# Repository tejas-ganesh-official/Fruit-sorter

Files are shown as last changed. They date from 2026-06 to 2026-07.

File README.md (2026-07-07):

# Fruit Sorter

AI-powered fruit sorting machine. An **ESP32-CAM** watches for fruit with an ultrasonic
sensor, snaps a photo, and sends it to a Telegram bot. A PC picks up the photo, classifies
it with a **PyTorch EfficientNetV2-S** model (`damaged` / `old` / `ripe` / `unripe`), and
tells a second **ESP32** to drive servo gates that drop the fruit into the correct bin
through a 3D-printed Y-chute.

---

## How it works

```mermaid
flowchart LR
    A[HC-SR04<br/>ultrasonic] -->|object detected| B[ESP32-CAM<br/>esp32cam_capture.ino]
    B -->|photo via HTTPS| C[Telegram bot]
    C -->|new photo| D[PC<br/>inference.py]
    D -->|EfficientNetV2-S<br/>predict label| D
    D -->|HTTP GET /data?label=&conf=| E[ESP32<br/>esp32_sorter.ino]
    E -->|drive servos| F[Y-chute<br/>Y_shape_v1.stl]
```

**Sorting logic** (`esp32_sorter.ino`):

| Prediction | Action | Bin |
|---|---|---|
| `old`, `damaged`  | Servo 1 | reject |
| `ripe`, `unripe`  | Servo 2 | keep |

> All three parts — ESP32-CAM, ESP32, and the PC running `inference.py` — must be on the
> **same Wi-Fi network**.

---

## Repository layout

```
fruit-sorter/
├── firmware/
│   ├── esp32cam_capture/      # AI-Thinker ESP32-CAM: ultrasonic trigger + photo -> Telegram
│   │   └── esp32cam_capture.ino
│   └── esp32_sorter/          # ESP32: receives label over HTTP, drives sorting servos
│       └── esp32_sorter.ino
├── ml/
│   ├── train.py               # PyTorch EfficientNetV2-S trainer (produces the .pth used below)
│   ├── inference.py           # Telegram listener + classifier + sends result to the sorter ESP32
│   ├── train_tf_mobilenet.py  # ALTERNATE trainer (TensorFlow/MobileNetV2) — see "Known gaps"
│   ├── requirements.txt       # main pipeline deps (PyTorch)
│   └── requirements-tf.txt    # only for the alternate TF trainer
├── hardware/
│   ├── wiring_diagram.png     # HC-SR04 <-> ESP32-CAM wiring
│   └── Y_shape_v1.stl         # 3D-printable sorting chute
├── LICENSE
└── README.md
```

---

## Wiring

HC-SR04 → ESP32-CAM (pins per `esp32cam_capture.ino`):

| HC-SR04 | ESP32-CAM |
|---|---|
| VCC | 5V |
| TRIG | GPIO 12 |
| ECHO | GPIO 14 |
| GND | GND |

Sorting servos → ESP32 (pins per `esp32_sorter.ino`):

| Servo | ESP32 |
|---|---|
| Servo 1 | GPIO 18 |
| Servo 2 | GPIO 19 |

> ⚠️ **ECHO is 5V logic, the ESP32 GPIO is 3.3V.** Put a divider on the ECHO line
> (e.g. 1kΩ + 2kΩ) or a level shifter so you don't stress the pin over time.

---

## Setup

### 1. Train the model (optional — only if you don't already have a `.pth`)

Arrange your images as an `ImageFolder`, one sub-folder per class:

```
dataset/
├── damaged/
├── old/
├── ripe/
└── unripe/
```

```bash
cd ml
pip install -r requirements.txt
python train.py --data ./dataset --epochs 15 --out fruit_efficientnetv2s.pth
```

This saves a checkpoint `inference.py` can load directly
(`{"model_state_dict": ..., "classes": [...]}`).

### 2. Flash the firmware (Arduino IDE)

Open each sketch from its own folder and fill in the blanks at the top:

- `firmware/esp32cam_capture/esp32cam_capture.ino` — Wi-Fi SSID/password, `BOTtoken`, `CHAT_ID`.
  Board: **AI Thinker ESP32-CAM**. Needs the `esp32` board package.
- `firmware/esp32_sorter/esp32_sorter.ino` — Wi-Fi SSID/password.
  Needs the **ESP32Servo** library. Note the local IP it prints on boot.

### 3. Run inference on the PC

```bash
cd ml
pip install -r requirements.txt
```

Fill in the config block at the top of `inference.py`:

- `api_id`, `api_hash` — from https://my.telegram.org
- `BOT_USERNAME` — your bot's username
- `MODEL_PATH` — path to your `.pth`
- `SAVE_DIR` — where incoming photos get saved
- `ESP32_IP` — the IP printed by `esp32_sorter.ino`

```bash
python inference.py
```

It listens for photos from your bot, classifies each one, and forwards the result to the
sorter ESP32.

---

## Known gaps / TODO

- **Two training scripts, two frameworks.** `train.py` is PyTorch (EfficientNetV2-S) and
  matches `inference.py`. `train_tf_mobilenet.py` is TensorFlow (MobileNetV2) and saves a
  `.h5` that **`inference.py` cannot load as-is** — it's kept as a reference/alternate only.
  If you want the TF path to be end-to-end, you'd need a matching TF inference script or an
  `.h5 → PyTorch` conversion. Use `train.py` for the working loop.
- **Secrets are placeholders.** Don't commit real Telegram/Wi-Fi credentials. The
  `.gitignore` already excludes the Telethon `*.session` file (it holds a login token for
  your Telegram account) and model weights.
- **Distance window is 1–5 cm** in `esp32cam_capture.ino` — tune `getDistance()` thresholds
  to your rig's geometry.
- **Model weights aren't included.** They're gitignored (large binaries). Ship them via a
  GitHub Release or Git LFS if you want them in the repo.

---

## License

MIT — see [LICENSE](LICENSE).

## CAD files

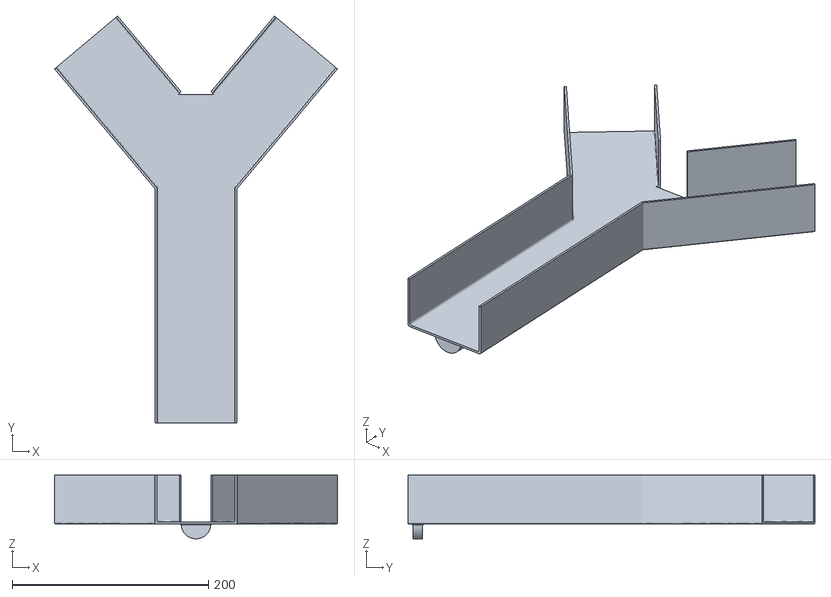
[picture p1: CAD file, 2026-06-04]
hardware/Y_shape_v1.stl
288.8 x 415.3 x 65.0

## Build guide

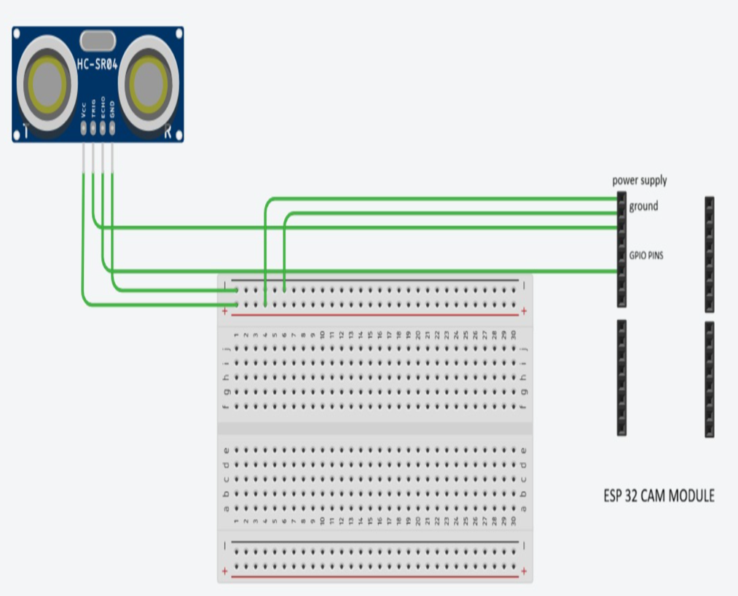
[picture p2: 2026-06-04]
hardware/wiring_diagram.png

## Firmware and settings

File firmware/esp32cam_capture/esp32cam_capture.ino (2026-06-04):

#include "esp_camera.h"
#include <WiFi.h>
#include <WiFiClientSecure.h>

const char* ssid = ""; //enter wifi id
const char* password = ""; //enter wifi password
//note that ESP32, ESP32 cam AND the machine in which you run the fetch_send file must all be in the same network

String BOTtoken = ""; //insert bot token
String CHAT_ID = ""; //insert chat id

WiFiClientSecure client;

// Ultrasonic pins
#define TRIG_PIN 12
#define ECHO_PIN 14

// AI Thinker ESP32-CAM pins
#define PWDN_GPIO_NUM     32
#define RESET_GPIO_NUM    -1
#define XCLK_GPIO_NUM      0
#define SIOD_GPIO_NUM     26
#define SIOC_GPIO_NUM     27
#define Y9_GPIO_NUM       35
#define Y8_GPIO_NUM       34
#define Y7_GPIO_NUM       39
#define Y6_GPIO_NUM       36
#define Y5_GPIO_NUM       21
#define Y4_GPIO_NUM       19
#define Y3_GPIO_NUM       18
#define Y2_GPIO_NUM        5
#define VSYNC_GPIO_NUM    25
#define HREF_GPIO_NUM     23
#define PCLK_GPIO_NUM     22

// -------- WiFi reconnect --------
void ensureWiFi() {
  if (WiFi.status() == WL_CONNECTED) return;

  Serial.println("WiFi reconnecting...");
  WiFi.begin(ssid, password);

  while (WiFi.status() != WL_CONNECTED) {
    delay(500);
    Serial.print(".");
  }

  Serial.println(" connected");
}

// -------- Camera --------
void startCamera() {

  camera_config_t config;

  config.ledc_channel = LEDC_CHANNEL_0;
  config.ledc_timer = LEDC_TIMER_0;

  config.pin_d0 = Y2_GPIO_NUM;
  config.pin_d1 = Y3_GPIO_NUM;
  config.pin_d2 = Y4_GPIO_NUM;
  config.pin_d3 = Y5_GPIO_NUM;
  config.pin_d4 = Y6_GPIO_NUM;
  config.pin_d5 = Y7_GPIO_NUM;
  config.pin_d6 = Y8_GPIO_NUM;
  config.pin_d7 = Y9_GPIO_NUM;

  config.pin_xclk = XCLK_GPIO_NUM;
  config.pin_pclk = PCLK_GPIO_NUM;
  config.pin_vsync = VSYNC_GPIO_NUM;
  config.pin_href = HREF_GPIO_NUM;

  config.pin_sscb_sda = SIOD_GPIO_NUM;
  config.pin_sscb_scl = SIOC_GPIO_NUM;

  config.pin_pwdn = PWDN_GPIO_NUM;
  config.pin_reset = RESET_GPIO_NUM;

  config.xclk_freq_hz = 20000000;
  config.pixel_format = PIXFORMAT_JPEG;

  config.frame_size = FRAMESIZE_UXGA;
  config.jpeg_quality = 10;

  config.fb_count = 1;
  config.fb_location = CAMERA_FB_IN_PSRAM;
  config.grab_mode = CAMERA_GRAB_LATEST;

  esp_err_t err = esp_camera_init(&config);

  if (err != ESP_OK) {
    Serial.printf("Camera init failed: 0x%x\n", err);
    return;
  }

  Serial.println("Camera initialized");
}

// -------- Distance --------
float getDistance() {

  digitalWrite(TRIG_PIN, LOW);
  delayMicroseconds(2);

  digitalWrite(TRIG_PIN, HIGH);
  delayMicroseconds(10);

  digitalWrite(TRIG_PIN, LOW);

  long duration = pulseIn(ECHO_PIN, HIGH, 30000);

  float distance = duration * 0.034 / 2;

  return distance;
}

// -------- Send Photo --------
bool sendPhoto() {

  delay(200);

  // Flush old buffered frames
  camera_fb_t * fb = NULL;

  for (int i = 0; i < 3; i++) {

    fb = esp_camera_fb_get();

    if (fb) {
      esp_camera_fb_return(fb);
      fb = NULL;
    }

    delay(100);
  }

  // Capture fresh frame
  fb = esp_camera_fb_get();

  if (!fb) {
    Serial.println("Camera capture failed");
    return false;
  }

  Serial.println("Connecting to Telegram...");

  if (!client.connect("api.telegram.org", 443)) {

    Serial.println("Telegram connection failed");

    esp_camera_fb_return(fb);

    return false;
  }

  String head =
    "--ESP32\r\n"
    "Content-Disposition: form-data; name=\"chat_id\";\r\n\r\n" +
    CHAT_ID +
    "\r\n--ESP32\r\n"
    "Content-Disposition: form-data; name=\"photo\"; filename=\"esp32.jpg\"\r\n"
    "Content-Type: image/jpeg\r\n\r\n";

  String tail = "\r\n--ESP32--\r\n";

  uint32_t totalLen = fb->len + head.length() + tail.length();

  client.println("POST /bot" + BOTtoken + "/sendPhoto HTTP/1.1");
  client.println("Host: api.telegram.org");
  client.println("Content-Length: " + String(totalLen));
  client.println("Content-Type: multipart/form-data; boundary=ESP32");
  client.println();

  client.print(head);

  client.write(fb->buf, fb->len);

  client.print(tail);

  esp_camera_fb_return(fb);

  client.stop();

  Serial.println("Fresh photo sent");

  return true;
}

void setup() {

  Serial.begin(115200);

  pinMode(TRIG_PIN, OUTPUT);
  pinMode(ECHO_PIN, INPUT);

  Serial.println();
  Serial.println("Connecting to WiFi...");

  WiFi.begin(ssid, password);

  while (WiFi.status() != WL_CONNECTED) {
    delay(500);
    Serial.print(".");
  }

  Serial.println();
  Serial.println("WiFi connected");

  Serial.print("IP Address: ");
  Serial.println(WiFi.localIP());

  client.setInsecure();

  startCamera();

  delay(2000);
}

unsigned long lastTrigger = 0;

void loop() {

  ensureWiFi();

  float distance = getDistance();

  Serial.print("Distance: ");
  Serial.println(distance);

  if (distance > 1 && distance < 5) {

    // 10 second cooldown
    if (millis() - lastTrigger > 10000) {

      Serial.println("Object detected!");

      if (!sendPhoto()) {

        Serial.println("Retrying...");

        sendPhoto();
      }

      lastTrigger = millis();
    }
  }

  delay(200);
}

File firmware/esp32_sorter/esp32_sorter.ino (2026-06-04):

#include <WiFi.h>
#include <WebServer.h>
#include <ESP32Servo.h>

// ===== WiFi =====
const char* ssid = ""; //wifi id
const char* password = ""; //wifi password

// ===== Server =====
WebServer server(80);

// ===== Servos =====
Servo servo1;
Servo servo2;

const int SERVO1_PIN = 18;
const int SERVO2_PIN = 19;

// ===== Handler =====
void handleData() {
  if (server.hasArg("label") && server.hasArg("conf")) {

    String label = server.arg("label");
    String conf = server.arg("conf");

    Serial.print("Prediction: ");
    Serial.print(label);
    Serial.print(" | Confidence: ");
    Serial.println(conf);

    // ===== SERVO LOGIC =====
    if (label == "old" || label == "damaged") {
      Serial.println("Activating Servo 1 → 270°");
      servo1.write(0);
      delay(4000);
      servo1.write(90);  // return to home

    } else if (label == "ripe" || label == "unripe") {
      Serial.println("Activating Servo 2 → 270°");
      servo2.write(90);
      delay(4000);
      servo2.write(0);  // return to home
    }

    server.send(200, "text/plain", "OK");

  } else {
    Serial.println("Invalid request");
    server.send(400, "text/plain", "Missing params");
  }
}

void setup() {
  Serial.begin(115200);

  // ===== Servo Setup =====
  servo1.attach(SERVO1_PIN);
  servo2.attach(SERVO2_PIN);
  servo1.write(90);
  servo2.write(0);

  // ===== WiFi =====
  WiFi.begin(ssid, password);
  Serial.print("Connecting");

  while (WiFi.status() != WL_CONNECTED) {
    delay(500);
    Serial.print(".");
  }

  Serial.println("\nConnected!");
  Serial.println(WiFi.localIP());

  server.on("/data", handleData);
  server.begin();

  Serial.println("Server started");
}

void loop() {
  server.handleClient();
}
